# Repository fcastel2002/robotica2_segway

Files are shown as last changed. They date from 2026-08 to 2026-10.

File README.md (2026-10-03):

# Segway con patas extensibles

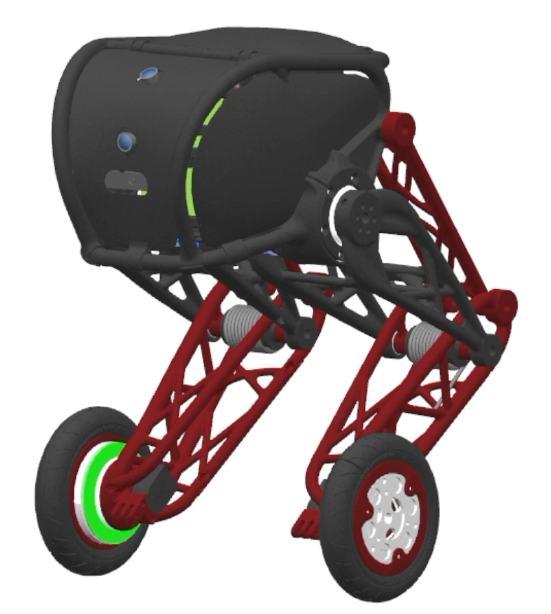
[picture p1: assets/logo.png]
Logo del robot


Trabajo final de **Robótica II**, Universidad Nacional de Cuyo (UNCUYO). Grupo 4: Joaquín Calderón
(modelado), Francisco Castel (diseño mecánico), Matías Armani (simulación en Simulink).

**Este archivo describe el robot tal como es hoy.** Todo lo que había de propuestas anteriores
(mecanismo de Hoeken, motores N20, plantas de simulación de agosto y principios de septiembre) se
borró del árbol el 19/9/2026 y quedó solo en la historia de git; ver la sección 7.

## 1. Qué es el robot

Un robot de dos ruedas que se equilibra como un péndulo invertido (tipo Segway) y que además tiene
**patas extensibles**: cada rueda cuelga de un mecanismo de cuatro barras movido por un servo, así
que el robot puede agacharse, pararse y bajar escalones absorbiendo el golpe con las patas.

- **Equilibrio y avance**: los dos motores de rueda, con encoder, controlados por un LQR sobre la
  inclinación y la velocidad (a diseñar sobre el modelo de la planta completa).
- **Patas**: un servo por pata. El servo es de posición; se le manda una trayectoria de ángulo y su
  lazo interno hace el par. La dinámica de la pata sirve para dimensionarlo, no para comandarlo.
- **Cabina**: caja impresa en PLA que lleva los dos servos, la batería y la electrónica. Los pivotes
  del cuatro barras (A, el eje del servo, y B) están en sus paredes laterales.

## 2. Números vigentes (19/9/2026)

Fuente única de todos los valores: [`modelado/parametros/parametros_fisicos.m`](modelado/parametros/parametros_fisicos.m),
variante `segunda_iteracion`. Si un número de este README no coincide con ese archivo, manda el archivo.

| | Valor | De dónde sale |
|---|---|---|
| Mecanismo | cuatro barras `A B C D` con acoplador rígido `C D P`; `P` es el eje de la rueda | `modelado/geometria/geometria_robot.png` |
| Barras | AD = 112, BC = 108, CD = 40,8, DP = 112 mm (familia 1,40 / 1,35 / 0,51 / 1,40 a escala 80); δ = 164° | medido en los STEP de `diseño_mecanico/segunda_iteracion/completo/step/` |
| Bancada AB | 80 mm a 45° (intención). En el STEP está en 77,9 mm a 46,6°: B quedó 3 mm corto en horizontal, a corregir en `cabeza_v31` | idem |
| Recorrido del servo | 320° (pata estirada, de pie) a 350° (plegada). En la dinámica se usa θ = 360° − servo: 10° plegada, 40° estirada | `parametros_geometria.m` |
| Rueda | Ø66 mm (Rw = 33), 30 g estimados | CAD |
| Servo de pata | **40 kg·cm**, ~58 g, uno por pata. Elegido el 19/9; verificar a qué tensión da los 40 kg·cm | decisión, ver sección 3 |
| Motor de rueda | **JGB37-520 12 V con encoder Hall**, ~152 g. Relación de reducción **sin definir** (la pieza del CAD es la de 319 rpm) | decisión, ver sección 3 |
| Masas estimadas | cabina 667 g (cabeza 207, tapa 114, servos 116, batería 120, electrónica 60, tornillería 50); pata 226 g (barras 44, rueda 30, motor 152); **robot ≈ 1,12 kg** | primera iteración escalada; **pesar todo** |
| Batería | LiPo 3S 11,1 V (propuesta) | |
| Control | 200 Hz (propuesta); electrónica por definir | |

Lo que sale de esos números (par estático del servo, inercia vista por el servo, altura de la cabina,
qué escalón se puede bajar, fuerzas en los pasadores) está en los PDF de `modelado/`, sección 4.

## 3. Decisiones tomadas y por qué

| Fecha | Decisión | Motivo | Dónde está |
|---|---|---|---|
| ago 2026 | Mecanismo de Hoeken con flexor → **cuatro barras** con acoplador rígido | el cuatro barras da una línea casi recta para el eje de rueda con un solo servo, y es más fácil de imprimir | `modelado/geometria/` |
| 2/9 | Barras en la familia 1,40 / 1,35 / 0,51 / 1,40 con δ = 164° | salió de un barrido de proporciones (scripts de Francisco, ya borrados; ver sección 7) | `parametros_fisicos.m` |
| 3/9 | Motor JGA25 de 60 rpm **descartado** | la simulación mostró que con 60 rpm el robot equilibra pero no puede desplazarse ni bajar escalones; hace falta encoder sí o sí | `base_conocimiento/dimensiones_cad_primera_iteracion.md` |
| 14/9 | CAD segunda iteración: barras a **escala 80** | la primera iteración tenía la bancada de 80 mm con barras de escala 100 y perdía la línea recta; Francisco llevó las barras a 80 | `diseño_mecanico/segunda_iteracion/` |
| 19/9 | El modelado pasa a escala 80 para seguir al CAD | eran dos ramas de la misma bifurcación; imprimir es lo caro, así que manda el CAD | `docs/gestion/2026-09-19-auditoria-limpieza.md`, sección 1.2 |
| 19/9 | Servo de **40 kg·cm** | con la geometría de escala 100 la caída de un escalón de 18 cm pedía 22,4 kg·cm de par medio; uno de 25 quedaba justo y uno de 35 no se consigue | `modelado/dinamica/dinamica_resumen.pdf`, sección 10 |
| 19/9 | Motor de rueda **JGB37-520 con encoder** | motorreductor con encoder integrado, 12 V, par de sobra para la rueda de 66 mm. Relación de reducción pendiente | sección 5 |
| 19/9 | `simulacion/planta_v2` (planta completa hecha con Claude) se descarta | el equipo va a rehacer la planta a mano en `modelado/planta/`; queda el banco Simulink de Matías | sección 7 |

## 4. Mapa del repositorio

Nuevo el 1/10/2026: [**modelo dinámico del péndulo invertido, desarrollado paso a paso**](modelado/planta/pendulo_invertido/desarrollo_matematico.md).
Representa el equilibrio y avance con las patas fijas en una postura configurable. La demostración
en MATLAB está en [`simulacion/pendulo_invertido/`](simulacion/pendulo_invertido/README.md); abrir
`SIMULAR_PENDULO_INVERTIDO.m` y pulsar Run. La planta conjunta con flexión dinámica sigue pendiente.

| Carpeta | Qué hay | Responsable |
|---|---|---|
| [`modelado/`](modelado/) | **El modelo del robot.** Una carpeta por tema: `geometria/` (figura con nombres y cotas), `cinematica/` (θ → posiciones, directa e inversa), `dcl/` (diagramas de cuerpo libre), `dinamica/` (Lagrange de la pata, tres casos, caída de escalón, fuerza en el eje del servo), `parametros/` (la fuente única de valores). Cada tema tiene su PDF con la deducción. Ver [`modelado/README.md`](modelado/README.md) | Joaquín (modelado), Matías (API y `parametros/`) |
| [`diseño_mecanico/`](diseño_mecanico/) | `segunda_iteracion/`: el CAD vigente (SolidWorks + STEP). `utilidades/`: piezas compradas (servo, horn, motor, tornillería). `primera_iteracion/`: solo el STEP y las propiedades másicas, que siguen siendo la fuente de las masas. `medir_step/`: scripts para medir el CAD sin SolidWorks. Ver [`diseño_mecanico/README.md`](diseño_mecanico/README.md) | Francisco |
| [`simulacion/`](simulacion/) | `dinamica_pata_v1/`: primera iteración del banco Simulink de la pata (Matías, 14 y 15/9), punto de entrada `INICIAR_DINAMICA_PATA.m`. Ver [`simulacion/README.md`](simulacion/README.md) | Matías |
| [`docs/gestion/`](docs/gestion/) | Plan, guía de QA y traspaso del banco Simulink; auditoría de limpieza del 19/9 | Matías, Joaquín |
| [`base_conocimiento/`](base_conocimiento/) | `dimensiones_cad_primera_iteracion.md`: cotas, masas, centros de masa e inercias medidos sobre el STEP de la primera iteración (2/9). Sigue vigente para masas; para cotas manda la segunda iteración | |
| [`guias_catedra/`](guias_catedra/) | Procedimientos de la cátedra (dimensionamiento de batería, preselección de servos) | |
| [`BACKLOG.md`](BACKLOG.md) | Lo hecho, lo en curso y lo pendiente, con evidencia. Es la lista de tareas del equipo | todos |
| [`AGENTS.md`](AGENTS.md) | Reglas para agentes y colaboradores (PDF → Markdown antes de leer, backlog, diagramas) | |
| `electronica/`, `firmware/`, `referencias/` | Vacías todavía | |

## 5. Qué falta (lo grande)

Detalle y estado en [`BACKLOG.md`](BACKLOG.md).

1. **Pesar** las piezas impresas, el servo y el motor, y reemplazar las masas estimadas.
2. **Definir la relación de reducción** del JGB37-520 y cargar su hoja de datos en `parametros_fisicos.m`.
3. **Medir el servo** en el banco: rigidez del lazo interno (grados de desvío por peso colgado) y par de
   calado real a la tensión que se use. De eso dependen todos los números de la caída de escalón.
4. Corregir en el CAD los 3 mm de la bancada (`cabeza_v31`) y agregar rueda, motor y tapa al ensamble
   de la segunda iteración, para poder cerrar la ficha de masas (CAD-201).
5. **Planta completa** en `modelado/planta/`: péndulo invertido sobre ruedas con la altura del centro de
   masa en función de θ, LQR, motores, contacto. Es el modelo del equilibrio; el banco de Matías es el
   de la pata.
6. Electrónica y firmware: nada empezado.

## 6. Cómo correr las cosas

- Figuras: `python modelado/<tema>/<figura>.py` genera el PNG al lado (Python 3 + matplotlib).
- Dinámica de la pata: abrir `modelado/dinamica/dinamica_pata.m` en MATLAB y correrlo. La sección 1
  tiene los parámetros para editar; las demás imprimen tablas y grafican.
- Tests: desde la raíz, `runtests('modelado/dinamica/tests')` y
  `runtests('simulacion/dinamica_pata_v1/tests')`.
- Banco Simulink: `simulacion/dinamica_pata_v1/INICIAR_DINAMICA_PATA.m` (ver su README).
- PDF: cada `*.tex` se compila con `pdflatex` dos veces desde su carpeta.
- Medir el CAD sin SolidWorks: `python diseño_mecanico/medir_step/step_cuatro_barras.py <ensamble.STEP>`.

## 7. Historia: lo que hubo antes y dónde encontrarlo

Hasta el 19/9 el repo arrastraba tres diseños anteriores y sus simulaciones, y cualquiera que entrara
(persona o IA) no sabía cuál era el vigente. Se borró todo lo anterior al cuatro barras y las plantas
de simulación descartadas. La lista completa, con el motivo de cada borrado, está en
[`docs/gestion/2026-09-19-auditoria-limpieza.md`](docs/gestion/2026-09-19-auditoria-limpieza.md).
Todo sigue en git: `git show eca3ed4:<ruta>` recupera cualquier archivo tal como estaba antes de la limpieza.

| Qué era | Dónde estaba | Por qué ya no |
|---|---|---|
| Mecanismo de Hoeken, robot de 800 g con rueda Ø80 y flexor (documento de dimensionamiento de agosto) | `base_conocimiento/Segway-Pata-Dimensionamiento.docx`, `simulacion/hoekens_dh.html` | reemplazado por el cuatro barras |
| Concepto con motores N20 y microservos SG90 | `diseño_mecanico/proof_of_concept/` | reemplazado |
| Primer boceto del cuatro barras y síntesis en MotionGen | `diseño_mecanico/4_bar_mechanism/`, `4 barras.motiongen` | reemplazado por `primera_iteracion` |
| GUI y barrido de proporciones de las barras (Francisco, 28/8) | `simulacion/simular_pata_segway.m`, `optimizar_barrido_local.m` | cumplieron su función; las proporciones quedaron en `parametros_fisicos.m` |
| CAD primera iteración (bancada 80 a 47,5°, barras 100) | `diseño_mecanico/primera_iteracion/*.SLDPRT` | reemplazado por la segunda; queda el STEP y las masas |
| Plantas Simulink `modelo_base`, `planta_v1` (borradas el 13/9) y `planta_v2` (19/9), con su manual y sus specs | `simulacion/`, `docs/informe_planta_v1/`, `docs/superpowers/` | el equipo rehace la planta a mano; queda el banco de Matías |
| Toolbox de Peter Corke copiado entero (120 MB) | `modelado/cinematica/rtb`, `smtb`, `common` | librería de terceros; `verificar_cinematica_4barras.m` sigue andando sin ella |

## 8. Convenciones

- Origen en A (eje del servo), y hacia arriba. En las figuras de la pata el frente del robot queda a la
  izquierda. Los segmentos se nombran por sus extremos: AB, AD, BC, CD, DP.
- Los PDF no se leen directamente: se convierten a Markdown primero (regla de [`AGENTS.md`](AGENTS.md)).
- Un valor físico vive en un solo lugar, `parametros_fisicos.m`. Las figuras de Python repiten las
  cinco cotas al principio de cada script porque no leen MATLAB; si cambian las barras, cambiarlas ahí también.

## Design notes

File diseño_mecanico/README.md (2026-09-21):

# diseño_mecanico

CAD del robot (SolidWorks 2026). Responsable: Francisco.

| Carpeta | Qué es |
|---|---|
| `segunda_iteracion/` | **El CAD vigente** (14/9/2026): cabina `cabeza_v31`, manivela `eslabon_AD_v2` + `eslabon_AD_tapa`, balancín `eslabon_BC` (interna y externa), acoplador `eslabon_CDP_v2`, servo y horn, tornillería. Ensambles `completo_v2` y `completo_v3`. En `completo/step/` están los STEP exportados de cada pieza y del ensamble, que es lo que puede leer quien no tiene SolidWorks |
| `utilidades/` | Piezas compradas: servo DS3225MG y su horn, motor JGB37-520, rueda de 65 mm, tuercas, tornillos y arandelas |
| `primera_iteracion/` | Solo `completo.STEP` y `mass_properties.md`. Es el CAD anterior (bancada 80 mm a 47,5°, barras a escala 100) y sigue siendo **la fuente de las masas e inercias** del modelo (`base_conocimiento/dimensiones_cad_primera_iteracion.md`) porque el ensamble nuevo no tiene rueda, motor ni tapa |
| `medir_step/` | Dos scripts de Python para medir el CAD sin SolidWorks: `step_agujeros.py <pieza.STEP>` lista los ejes de los agujeros de una pieza y las distancias entre ellos; `step_cuatro_barras.py <ensamble.STEP>` reconstruye el cuatro barras tal como está armado (A, B, C, D, P, largos, ángulo de la bancada, δ, θ de la pose) |

## Cotas de la segunda iteración, medidas sobre los STEP del 14/9

| Cota | Valor | Nota |
|---|---|---|
| AD, BC, CD, DP | 112, 108, 40,8, 112 mm | familia 1,40 / 1,35 / 0,51 / 1,40 a escala 80 |
| δ (D→C a D→P) | 164,0° | |
| AB | **77,9 mm a 46,6°** | la intención es 80 mm a 45°: B está a la altura justa (56,6 mm sobre A) pero 3 mm corto en horizontal (53,5 en vez de 56,6). **Pendiente corregir en `cabeza_v31`** |
| Pose armada | θ = 40,2° (pata estirada); P 148 mm por debajo de A | |
| Las dos patas | idénticas | en la primera iteración estaban en poses distintas |
| Cierre del mecanismo | 0,004 mm | los STEP son consistentes |

El modelo (`modelado/`) usa 80 mm a 45° para la bancada, es decir la intención y no el error de 3 mm.

## Pendientes para Francisco

1. Corregir los 3 mm de B en `cabeza_v31`.
2. Agregar rueda, motor JGB37-520 y tapa al ensamble de la segunda iteración, y exportar el STEP del
   conjunto, para poder cerrar la ficha de masas de esta iteración (CAD-201 del backlog).
3. `segunda_iteracion/` y `segunda_iteracion/completo/` tienen las mismas 19 piezas dos veces (la segunda es
   un Pack and Go con prefijo `asml_` y sufijo `v4`), y hay dos pares de ensambles (v2/v3). Dejar un solo
   juego de piezas y un solo ensamble; SolidWorks referencia por ruta, así que esto lo tiene que hacer quien
   tenga el CAD abierto.
4. La tornillería está repetida en `utilidades/`, `segunda_iteracion/` y `segunda_iteracion/completo/`.
   Dejar una biblioteca.
5. Después de cada cambio en el CAD: exportar los STEP a `completo/step/` y correr
   `python medir_step/step_cuatro_barras.py segunda_iteracion/completo/step/<ensamble>.STEP` para
   confirmar que las cotas siguen siendo las del modelo.

Los archivos `~$*.SLDPRT` que crea SolidWorks al abrir una pieza están en el `.gitignore`; no subirlos.

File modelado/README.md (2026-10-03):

# modelado

Modelo del Segway con patas, ordenado como la checklist de la cátedra: una carpeta por tema. En cada
carpeta hay a lo sumo tres tipos de archivo: un script de Python que genera la figura (`*.py` → `*.png`),
el código MATLAB (`*.m`) y un PDF con la deducción (`*.tex` → `*.pdf`).
El nuevo desarrollo del péndulo invertido se mantiene en Markdown, con ecuaciones y resultados enlazados.

**Geometría vigente: la segunda iteración del CAD (barras a escala 80).** Todo lo de esta carpeta se
actualizó a esa geometría el 19/9/2026. Los valores viven en `parametros/parametros_fisicos.m`; los
scripts de Python repiten las cinco cotas al principio porque no leen MATLAB.

| Carpeta | Qué tiene | Ítem de la checklist que cierra |
|---|---|---|
| `parametros/` | `parametros_fisicos.m`: **la única fuente de valores** (geometría, masas, inercias, servo, motor, contacto, sensores). Variante por defecto `segunda_iteracion`; `corregido` es el baseline histórico a escala 100 | Parámetros consolidados |
| `planta/pendulo_invertido/` | [Desarrollo matemático paso a paso](planta/pendulo_invertido/desarrollo_matematico.md), composición del cuerpo desde las piezas, dinámica no lineal sobre ruedas y linealización A/B. Dos coordenadas (`x`, `phi`), patas fijas en una postura configurable; [script de demostración](../simulacion/pendulo_invertido/SIMULAR_PENDULO_INVERTIDO.m) | Modelo dinámico del equilibrio y avance con patas fijas |
| `geometria/` | `geometria_robot.png`: el robot de perfil con los nombres de las barras (AB, AD, BC, CD, DP), los ángulos (45°, δ, θ) y las cotas del CAD | Diagrama cinemático y grados de libertad |
| `cinematica/` | `parametros_geometria.m` (adaptador de la fuente única, en mm y grados), `cinematica_directa.m` (θ → puntos A, B, C, D, P), `cinematica_inversa.m` (altura → θ), `cinematica_resumen.pdf`. Además `verificar_cinematica_4barras.m`, la verificación del grupo (anda sin el toolbox de Corke; si está instalado, además compara con él) | Cinemática directa e inversa |
| `dcl/` | `dcl_pata.png` (pata parada, θ = 10°, los tres cuerpos separados), `dcl_segway.png` (rueda y cuerpo del péndulo invertido), `dcl_resumen.pdf` con las ecuaciones de equilibrio y el par del servo calculado a mano | Diagramas de cuerpo libre; caso reproducido mediante cálculo manual |
| `dinamica/` | **`dinamica_apoyado.pdf`: el documento para leer**, paso a paso, solo el robot de pie, que es el caso que dimensiona el servo. `dinamica_resumen.pdf`: la referencia completa, con los tres casos (banco, parado, en el aire) y la caída de un escalón. `dinamica_pata.m`: todo el cálculo en un script (parámetros editables en la sección 1, tres casos, agacharse y pararse, verificación contra el DCL, caída de escalón, fuerza radial en el eje del servo). Además la API de Matías (`*_dinamica_pata.m`, con `tests/`) que alimenta el banco Simulink, y `demo_api_dinamica_pata.m` que la muestra. Figuras: `fig_dinamica.png` (los ángulos), `fig_apoyado.png` (alturas y coeficientes de velocidad), `fig_casos.png` (los tres casos) | Torque estático; masas y centros de masa; simulación mínima ejecutable; gráficos |

Convenciones comunes a todo: origen en A (eje del servo), y hacia arriba; θ es el ángulo de AD por
debajo de la horizontal (10° plegada, 40° estirada); el ángulo absoluto del servo que usa la cinemática es
360° − θ. En las figuras de la pata el frente del robot queda a la izquierda; en el DCL del Segway, a la
derecha (vista desde el otro lado).

Hay dos implementaciones de la misma física en `dinamica/`: las funciones locales de `dinamica_pata.m`
(con fricción por pivote, caída de escalón y reacciones) y la API de Matías (más simple, con tablas para
Simulink). Las dos leen los mismos parámetros. Si se cambia una ecuación, cambiarla en las dos.

Desde el 1/10/2026, `planta/pendulo_invertido/` desarrolla el equilibrio con patas fijas. Recalcula el
centro de masa y la inercia al elegir otra postura. El siguiente paso es la planta conjunta con flexión
dinámica de patas, motor eléctrico y control; sustituir una altura variable en el modelo reducido no
incorpora por sí solo ese acoplamiento.

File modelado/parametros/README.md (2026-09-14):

# Parámetros físicos comunes

`parametros_fisicos.m` es la única fuente editable de geometría, masas, inercias, actuadores,
contacto, sensores y ambiente que hoy comparten cinemática, dinámica y simulación.

Las variantes disponibles son:

- `cad`: primera iteración tal como fue medida, con bancada de 80 mm a 47,5°;
- `corregido`: baseline nominal de trabajo, con bancada de 100 mm a 45°.

La segunda iteración CAD no se incorporará hasta contar con cotas y propiedades másicas verificadas.
Los consumidores deben convertir estos valores de ingeniería a SI en sus adaptadores y no volver a
copiar números físicos en otros archivos.

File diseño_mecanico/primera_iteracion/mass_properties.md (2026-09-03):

Mass properties of completo
  Configuration: Predeterminado
  Coordinate system: -- default --

* Includes the mass properties of one or more hidden components/bodies.

Mass = 587.71 grams

Volume = 525422.05 cubic millimeters

Surface area = 299209.35 square millimeters

Center of mass: ( millimeters )
          X = -7.31
          Y = -38.28
          Z = 991.16

Principal axes of inertia and principal moments of inertia: ( grams * square millimeters )
aken at the center of mass.
T
            Ix = (-0.04, 0.99, 0.15)       Px = 3284250.26
            Iy = (-1.00, -0.05, 0.02)      Py = 5222569.89
            Iz = ( 0.03, -0.14, 0.99)      Pz = 6703769.87

Moments of inertia: ( grams * square millimeters )
aken at the center of mass and aligned with the output coordinate system. (Using positive tensor notation.)
T
          Lxx = 5219871.31 Lxy = -79137.38          Lxz = -52793.69
          Lyx = -79137.38      Lyy = 3360073.02     Lyz = 490590.07
          Lzx = -52793.69      Lzy = 490590.07      Lzz = 6630645.69

Moments of inertia: ( grams * square millimeters )
aken at the output coordinate system. (Using positive tensor notation.)
T
          Ixx = 583453919.84 Ixy = 85223.43          Ixz = -4308509.55
          Iyx = 85223.43        Iyy = 580764282.48 Iyz = -21808236.30
          Izx = -4308509.55 Izy = -21808236.30 Izz = 7523221.06

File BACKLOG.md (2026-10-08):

# Backlog persistente — Segway con piernas extensibles

Última actualización: 2026-10-04. Este archivo es la fuente de verdad del trabajo realizado,
en curso y pendiente. Todo cambio futuro debe actualizar aquí su estado y adjuntar evidencia.

Estados: `HECHO`, `EN CURSO`, `PENDIENTE`, `BLOQUEADO`. Prioridades: `P0` crítica, `P1` alta,
`P2` media, `P3` baja.

Plan vigente: [integración de la dinámica en Simulink](docs/gestion/2026-09-14-plan-dinamica-simulink.md).
Traspaso vigente: [dinámica de pata en Simulink](docs/gestion/2026-09-15-handoff-dinamica-simulink.md).

## Estado ejecutivo

- La dinámica de la pata entregada en el commit `c5602f1` es ejecutable y consistente con la
  cinemática y el DCL para los supuestos declarados.
- El banco reducido `simulacion/dinamica_pata_v1/` ya está construido, es regenerable desde código y
  reproduce `banco`, `parado` y `aire`: 12/12 pruebas propias aprobadas.
- El equipo dispone de un único acceso público, `INICIAR_DINAMICA_PATA.m`; el `.slx`, README, pruebas y
  resultados quedan visibles, mientras que constructores y adaptadores se concentran en `interno/`.
- La comunicación visual se limita a tres PNG estables: último Run, comparativo del barrido y validación
  energética. Las métricas completas permanecen en MATLAB sin generar gráficos auxiliares.
- `simulacion/planta_v2/` se eliminó el 19/9 por decisión de Joaquín: la planta completa se rehace a mano en
  `modelado/planta/`. Desde el 1/10 se suma el péndulo invertido con patas fijas al banco de la pata.
- El [péndulo invertido sobre ruedas](modelado/planta/pendulo_invertido/desarrollo_matematico.md) tiene
  deducción completa, cuerpo equivalente calculado desde las piezas, modelo no lineal y linealización A/B.
  [Demostración MATLAB](simulacion/pendulo_invertido/SIMULAR_PENDULO_INVERTIDO.m) ejecutada en R2025b:
  [6/6 grupos físicos aprobados](simulacion/pendulo_invertido/resultados/verificacion.json), cinco archivos
  sin avisos del analizador; faltan la flexión dinámica, la identificación del motor y el control.
- MATLAB R2023b Update 6, Simulink 23.2 y los toolboxes necesarios están instalados.
- Codex usa MATLAB MCP Server v0.13.0 y Simulink Agentic Toolkit 2026.09. La compuerta de librerías
  devuelve `found=false`, `gatePass=true`; `model_overview`, `model_read` y `model_check` funcionan.
- La auditoría MCP del banco terminó `healthy`: sin puertos ni líneas desconectadas. Se corrigieron
  tres líneas huérfanas creadas al vaciar los subsistemas predeterminados.
- Desde el 19/9 la variante por defecto de `parametros_fisicos.m` es `segunda_iteracion` (barras a escala 80,
  servo de 40 kg·cm, motor JGB37-520 de 152 g). Con ella pasan los 8 tests del núcleo y los 4 del banco Simulink.
- El CAD de `segunda_iteracion/` tiene las barras a escala 80 (medido el 19/9 sobre los STEP con
  `diseño_mecanico/medir_step/`); el modelado ya lo sigue. Faltan en el ensamble la rueda, el motor y la tapa,
  así que las masas siguen siendo las de la primera iteración escaladas: pesar las piezas es la primera pendiente.

## Trabajo realizado

| ID | Pri. | Estado | Fecha | Tarea | Evidencia / resultado |
|---|---:|---|---|---|---|
| PEN-001 | P0 | HECHO | 2026-10-01 | Desarrollar el péndulo invertido sobre ruedas, con patas fijas configurables, deducción paso a paso y script MATLAB legible (Codex) | [Capítulo matemático](modelado/planta/pendulo_invertido/desarrollo_matematico.md), [script](simulacion/pendulo_invertido/SIMULAR_PENDULO_INVERTIDO.m), [corrida](simulacion/pendulo_invertido/resultados/resultado_base.md), [6/6 comprobaciones físicas](simulacion/pendulo_invertido/resultados/verificacion.json); MATLAB R2025b, cinco archivos con 0 avisos; CoM/inercia recalculados para 10°, 25° y 40°; alcance de patas fijas explícito |
| PEN-002 | P1 | HECHO | 2026-10-03 | Cambiar la convención del péndulo invertido a sentido antihorario positivo (ángulos, pares y momentos) en el capítulo, el modelo MATLAB y la verificación | [Capítulo](modelado/planta/pendulo_invertido/desarrollo_matematico.md) §3 y ecs. (9)–(56), [verificación 6/6](simulacion/pendulo_invertido/resultados/verificacion.json), [corrida regenerada](simulacion/pendulo_invertido/resultados/resultado_base.md) con A/B iguales a (56); MATLAB R2025b |
| PEN-003 | P1 | HECHO | 2026-10-04 | Redactar el desarrollo del péndulo invertido centrado en el espacio de estados (sin scripts), estilo libro, con diagramas svgbob; responde por qué el capítulo previo no lo usa, el atajo de linealización por energías y el seno como perturbación medida con IMU | [Capítulo](modelado/planta/pendulo_invertido/desarrollo_espacio_estados.md), [diagramas](modelado/planta/pendulo_invertido/diagramas/) (`.bob`/`.svg`/`.png`); A, B y autovalores iguales a la [corrida base](simulacion/pendulo_invertido/resultados/resultado_base.md); determinante de controlabilidad, cero RHP, observabilidad con solo IMU, cancelación de gravedad y ganancias del lazo interno verificados numéricamente con numpy (fuera del repo); contrastado el 2026-10-04 con las págs. 3-12/3-13, 7-4/7-5 y 14-11 a 14-15 del libro de Åström–Murray (sin discrepancias; se corrigió la cota del cero RHP a 0,6·z₀); sin ejecutar MATLAB |
| DOC-104 | P2 | HECHO | 2026-10-04 | Eliminar de `AGENTS.md` la regla que prohibía leer PDFs directamente, por decisión explícita del usuario (Francisco Castel) | [`AGENTS.md`](AGENTS.md) sin la sección «Regla obligatoria para archivos PDF»; se borró la conversión intermedia `referencias/_md/` (no versionada) |
| AUD-001 | P0 | HECHO | 2026-09-14 | Inventariar repositorio, historia y estructura sin leer PDFs directamente | Revisión de archivos fuente `.md`, `.tex` y `.m`; PDFs omitidos según `AGENTS.md` |
| AUD-002 | P0 | HECHO | 2026-09-14 | Revisar el commit de dinámica de `joacalde` | Commit `c5602f1`: tres casos `banco`, `parado`, `aire`; ecuación de Lagrange, DCL y simulación ODE |
| AUD-003 | P0 | HECHO | 2026-09-14 | Ejecutar y analizar `dinamica_pata.m` | MATLAB sin errores ni avisos de `checkcode`; 11,62 kg·cm estático, 16,2 kg·cm pico en maniobra |
| AUD-004 | P0 | HECHO | 2026-09-14 | Comparar dinámica y cinemática independiente | Error máximo en la posición de `P`: `3,735e-16 m` |
| AUD-005 | P0 | HECHO | 2026-09-14 | Ejecutar regresión de `simulacion/planta_v2/tests` | 21/22 pasan; falla `test_bloques/test_escalera_y_flexor`, error de posición final `0,0670 m` > `0,05 m` |
| AUD-006 | P1 | HECHO | 2026-09-14 | Restaurar artefactos `.slx` regenerados por las pruebas | Worktree devuelto al estado previo antes de crear esta documentación |
| ENV-001 | P0 | HECHO | 2026-09-14 | Auditar MATLAB/Simulink y toolboxes | MATLAB R2023b Update 6; Simulink, Symbolic Math, Control System, Simscape Multibody y Simulink Test 23.2 |
| MCP-001 | P0 | HECHO | 2026-09-14 | Auditar MCP instalado y versión upstream | Claude usa `C:/Users/matia/.claude/matlab-mcp-core-server.exe` v0.10.0; Codex: ninguno; upstream: v0.13.0 |
| DOC-001 | P0 | HECHO | 2026-09-14 | Crear plan y backlog persistentes | Este archivo y `docs/gestion/2026-09-14-plan-dinamica-simulink.md` |
| PAR-001 | P0 | EN CURSO | 2026-09-19 | Consolidar parámetros físicos compartidos | Variante `segunda_iteracion` (escala 80, servo 40 kg·cm, JGB37-520) por defecto desde el 19/9; Python y `.tex` de `modelado/` actualizados; resta cargar masas pesadas y la relación del motor |
| DYN-101 | P0 | HECHO | 2026-09-14 | Convertir la derivación en API reutilizable | Funciones públicas de parámetros, términos, estado, normal, modos y tablas en `modelado/dinamica/`; script histórico conservado como demo |
| DYN-102 | P0 | HECHO | 2026-09-14 | Formalizar `n_patas` | Eliminado el factor fijo `2`; equivalencia para dos patas y caso de tres patas cubiertos por tests |
| DYN-104 | P1 | HECHO | 2026-09-14 | Generar tablas trazables para Simulink | Seis tablas 2-D (`theta`, caso), comparadas contra las funciones directas con error controlado |
| SIM-101 | P0 | HECHO | 2026-09-14 | Construir el banco reducido Simulink | `dinamica_pata_simulink.slx`, generador, escenarios, runner, pruebas y README en `simulacion/dinamica_pata_v1/` |
| SIM-102 | P0 | HECHO | 2026-09-14 | Implementar las tres reducciones | `banco`, `parado` y `aire` comparten la misma ecuación y seleccionan tablas por caso |
| SIM-103 | P0 | HECHO | 2026-09-14 | Auditar estructura mediante MCP | `model_overview`/`model_read`: 3 subsistemas internos; `model_check`: `healthy`, sin advertencias |
| TST-101 | P0 | HECHO | 2026-09-14 | Verificar MATLAB vs Simulink | Errores suaves máximos por debajo de `1e-5 rad` y `1e-4 rad/s`; términos estáticos coincidentes |
| TST-102 | P1 | HECHO | 2026-09-14 | Verificar energía y sensibilidad al solver | Deriva conservativa `7,79e-10`; residuo disipativo `3,76e-8`; comparación de tres configuraciones documentada |
| RUN-101 | P1 | HECHO | 2026-09-14 | Ejecutar el primer barrido reproducible | `simulacion/dinamica_pata_v1/resultados/corridas_baseline_2026-09-14.mat` y resumen Markdown |
| ARC-101 | P0 | HECHO | 2026-09-15 | Priorizar bloques nativos y legibilidad visual en el banco reducido | Cero bloques `MATLAB Function`; `test_construccion_reproducible` verifica la condición |
| DOC-102 | P1 | HECHO | 2026-09-15 | Documentar apertura, ejecución, interpretación y QA del banco | [Guía de QA](docs/gestion/2026-09-15-guia-qa-dinamica-simulink.md) con comandos copiables, diagnóstico de `Invalid expression`, umbrales y checklist |
| DOC-103 | P0 | HECHO | 2026-09-15 | Preparar traspaso autocontenido para continuar la dinámica Simulink en una sesión limpia | [Documento de traspaso](docs/gestion/2026-09-15-handoff-dinamica-simulink.md) con origen, arquitectura, comandos, evidencia, limitaciones, estado Git y próximos pasos; QA final 12/12 |
| ORG-101 | P0 | HECHO | 2026-09-15 | Consolidar el banco en un punto de entrada único y separar detalles internos | [`INICIAR_DINAMICA_PATA.m`](simulacion/dinamica_pata_v1/INICIAR_DINAMICA_PATA.m), [`interno/`](simulacion/dinamica_pata_v1/interno/), 12/12 pruebas y ejecución directa con Run verificadas |
| VIS-101 | P0 | HECHO | 2026-09-15 | Generar figuras automáticas y comunicables después de cada Run, barrido y análisis energético | [`resultados/figuras/README.md`](simulacion/dinamica_pata_v1/resultados/figuras/README.md), [`resumen_equipo.png`](simulacion/dinamica_pata_v1/resultados/figuras/resumen_equipo.png), [`energia_solver.png`](simulacion/dinamica_pata_v1/resultados/figuras/energia_solver.png); botón Run verificado y QA 12/12 aprobado |
| VIS-102 | P1 | HECHO | 2026-09-15 | Simplificar la exportación visual para conservar únicamente PNG | Exportador validado con 0 avisos; regeneración produjo 12 PNG y ningún PDF/FIG; se retiraron 24 artefactos redundantes de [`resultados/figuras/`](simulacion/dinamica_pata_v1/resultados/figuras/) |
| VIS-103 | P1 | HECHO | 2026-09-15 | Reducir sobregráficos y análisis visual redundante | Tres PNG estables en [`resultados/figuras/`](simulacion/dinamica_pata_v1/resultados/figuras/): Run con ángulo/esfuerzo/contacto/KPI, barrido con tres márgenes y energía con dos verificaciones; se retiraron nueve PNG redundantes |
| AUD-007 | P0 | HECHO | 2026-09-19 | Auditar contenido obsoleto y coherencia CAD ↔ modelado | [Auditoría de limpieza](docs/gestion/2026-09-19-auditoria-limpieza.md): conflicto de git commiteado en `dinamica_pata.m` (`eca3ed4`, versión limpia en el stash `661c39f`); CAD de segunda iteración a escala 80 (AB 77,9 mm a 46,6°, AD 112, BC 108, CD 40,8, DP 112) contra modelado a escala 100; lista de borrado por nivel de seguridad. Nada borrado todavía |
| FIX-001 | P0 | HECHO | 2026-09-19 | Resolver el conflicto de git commiteado en `dinamica_pata.m` | Restaurado desde el stash `661c39f` (444 líneas, sin marcadores); el demo de Matías quedó en `demo_api_dinamica_pata.m` |
| LIM-001 | P0 | HECHO | 2026-09-19 | Borrar todo lo anterior al cuatro barras, las plantas descartadas y los duplicados | Corke vendoreado, OneNote, `proof_of_concept`, `4_bar_mechanism`, Hoeken, scripts de síntesis, `informe_planta_v1`, specs, `.codebase-memory`, locks de SolidWorks, primera iteración (salvo STEP y masas), `planta_v2` (su `git rm` lo ejecuta Joaquín: bloqueado por permisos del agente). README raíz y de cada carpeta reescritos |
| PAR-002 | P0 | HECHO | 2026-09-19 | Pasar todo `modelado/` a la geometría del CAD (escala 80) con el motor y el servo elegidos | 7 figuras regeneradas, 4 PDF recompilados, `dinamica_pata.m` corrido: 9,06 kg·cm estático, 19,9 kg·cm para 18 cm de escalón (límite 47 cm con 40 kg·cm), tests 8/8 y Simulink 4/4 |
| ELE-001 | P1 | HECHO | 2026-09-22 | Investigar corriente del JGB37-520 y aptitud preliminar del DRV8871 | [Comparación con fichas de fabricante y TI](electronica/seleccion_driver_jgb37_520.md): 12 V/319 rpm ≈ 0,17 A nominales y 1,2 A bloqueado en una variante; 3,6 A del driver son de pico; confirmar bobinado real |
| ELE-002 | P1 | PENDIENTE | 2026-09-22 | Confirmar la relación del motor elegido y validar driver con medidas eléctricas y térmicas | [Publicación concreta y criterios](electronica/seleccion_driver_jgb37_520.md): 12 V, ≤1 A nominal, 2,3 A bloqueado; anuncio ofrece varias relaciones sin fijar la entregada |
| ELE-003 | P1 | HECHO | 2026-09-22 | Investigar corriente publicada del servo de 40 kg·cm elegido | [Registro de la publicación y comparación](electronica/servo_40kg_corriente.md): ficha «Genérica / Generic» sin tensión ni corriente; no hay máximo verificable para este producto |
| ELE-004 | P1 | PENDIENTE | 2026-09-22 | Obtener ficha o medir el servo comprado y dimensionar su alimentación | [Datos pendientes y margen provisional](electronica/servo_40kg_corriente.md); dos servos por robot, medir pico y carga simultánea |
| ELE-005 | P1 | HECHO | 2026-09-22 | Proponer fusibles de compra para LiPo 3S, motores y BEC | [Cálculo y ubicación](electronica/fusibles_propuesta_inicial.md): 15 A principal, 5 A por motor, 10 A entrada de BEC, sujetos a calibre de cables y corriente de entrada del BEC definitivo |
| ELE-006 | P1 | HECHO | 2026-09-22 | Revisar conexión INA219 con ESP32 y compatibilidad del carrito | [Conexión, límites y ajustes de compra](electronica/ina219_esp32_y_carrito.md), basados en la [planilla de materiales](Materiales%20-%20Segway%20-%20Robotica%202.xlsx), las capturas y fichas oficiales de TI/Espressif; pendiente de validación física: corriente real y capacidad de los módulos genéricos |
| ELE-007 | P1 | HECHO | 2026-09-22 | Definir alimentación de DRV8871 desde LiPo 3S y protección de batería | [Distribución, BMS y conector](electronica/alimentacion_lipo_3s.md): VM directo a 3S; balanceo y protección por subtensión externos; Mini-Tamiya de la batería elegida difiere del XT60 previsto |
| ELE-008 | P1 | HECHO | 2026-09-22 | Verificar alcance de INA226, alarma y BMS 3S para LiPo del carrito | [Criterio revisado](electronica/ina226_bms_3s.md): foto confirma `R100`, `VBUS` y `ALERT`; válido como alarma de tensión total sin corriente por shunt; para corriente total requiere shunt y camino de potencia distintos; operación autónoma requiere corte por celda |
| ELE-009 | P1 | HECHO | 2026-09-22 | Evaluar ACS712 para corriente de motores y batería con ESP32 | [Selección y conexión](electronica/medicion_corriente_acs712.md): dos ±5 A por motor y uno ±20 A total, condicionados a la capacidad de los módulos; divisores 1:2 a ADC1 del ESP32, calibración y filtrado |
| ELE-010 | P2 | HECHO | 2026-09-22 | Aclarar mediciones simultáneas de tensión, corriente y potencia del INA226 en la rama de 5 V | [Funcionamiento y conexión](electronica/ina226_bms_3s.md): VBUS y shunt son mediciones directas; corriente/potencia requieren calibración; R100 útil en lógica 5 V solo si pico <0,819 A; dos módulos I²C requieren direcciones distintas |
| ELE-011 | P1 | HECHO | 2026-09-22 | Dimensionar INA226 para dos ramas de motor y reutilizar VBUS para batería | [Propuesta de dos módulos](electronica/ina226_dos_motores.md): R010 por rama, VBUS común para LiPo, ubicación en VM, direcciones distintas; corriente medida es la entrada del driver, no la instantánea del bobinado |
| ELE-012 | P1 | HECHO | 2026-09-22 | Evaluar resistencias de cemento de 5 W como shunts externos del INA226 | [Evaluación del surtido](electronica/ina226_dos_motores.md): 0,01 Ω/5 W utilizable para prototipo, condicionado a conexión Kelvin y calibración; preferir shunts de cuatro terminales y 1 % para montaje definitivo |

## Próximo hito: banco Simulink de la dinámica de la pata

| ID | Pri. | Estado | Dependencias | Tarea | Criterio de aceptación |
|---|---:|---|---|---|---|
| CAD-201 | P0 | EN CURSO | Equipo mecánico | Exportar la segunda iteración a STEP y registrar cotas, masas, CoM e inercias por pieza | Cotas medidas el 19/9 sobre los STEP del 14/9 (AD 112, BC 108, CD 40,8, DP 112; AB 77,9 mm a 46,6°, B 3 mm corto) con `diseño_mecanico/medir_step/`; faltan rueda, motor y tapa en el ensamble para las masas |
| PAR-001 | P0 | EN CURSO | 2026-09-19 | Consolidar parámetros físicos compartidos | Variante `segunda_iteracion` (escala 80, servo 40 kg·cm, JGB37-520) por defecto desde el 19/9; Python y `.tex` de `modelado/` actualizados; resta cargar masas pesadas y la relación del motor |
| MCP-002 | P0 | HECHO | 2026-09-14 | Instalar/actualizar MATLAB MCP Server v0.13.0 y Simulink Agentic Toolkit para Codex | Servidor v0.13.0, toolkit 2026.09, 24 skills; `detect_matlab_toolboxes` y `model_overview` invocados desde una sesión Codex nueva |
| MCP-003 | P0 | HECHO | 2026-09-14 | Configurar Windows y tiempos de espera | Modo `existing`, `env_vars = ["WINDIR"]`, telemetría deshabilitada, `startup_timeout_sec = 60` y `tool_timeout_sec = 600`; ver [registro](docs/gestion/2026-09-14-entorno-matlab-mcp.md) |
| DYN-101 | P0 | HECHO | PAR-001 | Separar el script monolítico en funciones reutilizables | API pública y demo disponibles; 8/8 tests del núcleo aprobados |
| DYN-102 | P0 | HECHO | DYN-101 | Eliminar supuestos codificados como `2` y formalizar `n_patas` | Resultados idénticos para `n_patas=2`; prueba coherente con `n_patas=3` aprobada |
| DYN-103 | P0 | EN CURSO | DYN-101 | Añadir límites físicos y señal explícita de pérdida de contacto | Topes y supervisor MATLAB implementados; resta transición automática `parado` ↔ `aire` y prueba de recontacto en Simulink |
| DYN-104 | P1 | HECHO | DYN-101 | Generar tablas trazables de `Ieq`, `dIeq`, `dV`, `wP` y cinemática | Error de tabla < 0,1 % frente a cálculo directo en toda la carrera; variante y datos fuente registrados |
| SIM-101 | P0 | HECHO | DYN-101, DYN-104 | Construir `simulacion/dinamica_pata_v1/dinamica_pata_simulink.slx` | Modelo regenerable, abre, compila y corre en R2023b; interfaces documentadas |
| SIM-102 | P0 | HECHO | SIM-101 | Implementar los tres bancos reducidos como variantes de validación | `banco`, `parado` y `aire` reproducen los términos MATLAB sin ecuaciones duplicadas |
| TST-101 | P0 | HECHO | SIM-101 | Crear pruebas MATLAB vs Simulink | Casos suaves: `theta < 1e-5 rad`, `dtheta < 1e-4 rad/s`; suite de equivalencia aprobada |
| TST-102 | P1 | HECHO | SIM-101 | Verificar conservación/disipación de energía y sensibilidad al solver | Resultado y MAT en `simulacion/dinamica_pata_v1/resultados/`; solver nominal respaldado para dinámica suave |
| TST-103 | P0 | PENDIENTE | DYN-103 | Verificar topes, pérdida de contacto y recontacto como eventos híbridos | Sin normal negativa silenciosa; secuencia de modos y penetración máxima documentadas |
| CTL-101 | P1 | PENDIENTE | TST-101 | Evaluar prealimentación de gravedad en el servo del banco | Error estático en 10°, 25° y 40° cuantificado y reducido sin ocultar saturaciones |
| RUN-101 | P1 | HECHO | TST-101 | Ejecutar barridos básicos de maniobra y parámetros | `.mat` y resumen `.md` versionables con parámetros, solver y commit base registrados |

## Integración con la planta completa

| ID | Pri. | Estado | Dependencias | Tarea | Criterio de aceptación |
|---|---:|---|---|---|---|
| V2-001 | P0 | CANCELADO | — | Diagnosticar la prueba fallida `escalera_flexor` | `planta_v2` eliminada el 19/9 (decisión de Joaquín; ver [auditoría](docs/gestion/2026-09-19-auditoria-limpieza.md)) |
| V2-002 | P0 | CANCELADO | — | Resolver la edición manual del `.slx` no reflejada por su constructor | `planta_v2` eliminada el 19/9 |
| PLT-301 | P0 | PENDIENTE | TST-101, V2-001 | Especificar planta exacta con `q=[x_P,y_P,phi,theta]` | Documento de ecuaciones, convenciones y balance de energía aprobado |
| PLT-302 | P0 | PENDIENTE | PLT-301 | Derivar/generar `M(q)`, términos centrífugos/Coriolis, gravedad y fuerzas generalizadas | Matriz simétrica definida positiva en toda la carrera; tres reducciones coinciden con DYN-101 |
| PLT-303 | P0 | PENDIENTE | PLT-302 | Crear la planta completa en `modelado/planta/` (a mano, sin heredar `planta_v2`) y después su banco en `simulacion/` | Piso plano sin control y casos reducidos pasan; artefactos regenerables desde código |
| PLT-304 | P1 | PENDIENTE | PLT-303 | Integrar contacto, ruedas, motores, batería, sensores y controlador existentes | Interfaces equivalentes o migración documentada; sin señales algebraicas ocultas |
| CTL-301 | P0 | PENDIENTE | PLT-304 | Relinealizar y rediseñar el LQR en varios largos de pata | Controlabilidad verificada; márgenes, saturación y puntos de operación versionados |
| TST-301 | P0 | CANCELADO | — | Regresión `planta_v2` vs `planta_v3` en piso plano | Sin `planta_v2` no hay regresión heredada; la planta nueva se valida contra el DCL y la dinámica de la pata |
| RUN-301 | P1 | PENDIENTE | CTL-301, TST-301 | Simular equilibrio, empujones, agacharse/pararse y avance | Métricas y gráficas versionadas; casos nominales y extremos |
| RUN-302 | P1 | PENDIENTE | RUN-301 | Simular escalón y escalera con/sin flexor | Solo después de validar contacto y piso plano; impacto y sensibilidad al paso documentados |
| VAL-301 | P1 | PENDIENTE | Prototipo físico | Identificar parámetros reales de servo, rueda, contacto y masas | Ensayos y datos crudos versionados; parámetros actualizados con incertidumbre |
| DOC-301 | P1 | PENDIENTE | RUN-302 | Actualizar informe y manual del modelo | Ecuaciones, supuestos, trazabilidad y resultados concordantes con `planta_v3` |

## Reglas de mantenimiento

1. Al iniciar una tarea, cambiarla a `EN CURSO`, agregar fecha y responsable.
2. Al finalizar, enlazar evidencia reproducible y recién entonces marcar `HECHO`.
3. Si aparece trabajo nuevo, asignar un ID estable; no ocultarlo dentro de comentarios del código.
4. Los resultados deben indicar versión de parámetros, variante CAD, solver, tolerancias y commit.
5. Los PDFs no son fuente de lectura: usar el `.md` o `.tex` editable correspondiente.

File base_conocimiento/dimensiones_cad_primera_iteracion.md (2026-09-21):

# Dimensiones y propiedades másicas del CAD — `primera_iteracion` (2026-09-02)

> **Nota (19/9/2026):** las cotas de este documento son de la primera iteración y quedaron superadas por
> `diseño_mecanico/segunda_iteracion` (barras a escala 80: AD 112, BC 108, CD 40,8, DP 112; ver
> `diseño_mecanico/README.md`). Las masas, centros de masa e inercias de las secciones 6 y 7 siguen siendo la
> única fuente disponible; `modelado/parametros/parametros_fisicos.m` las escala a 80.

Fuente: `diseño_mecanico/primera_iteracion/completo.STEP` (SolidWorks 2026, AP203).
Método: parseo del STEP (posiciones de ensamble y centros de agujeros) + mallado tetraédrico en
MATLAB R2023b (`importGeometry` + `generateMesh`) para volumen, centroide e inercia de cada pieza.
SolidWorks no está instalado en la PC de trabajo, así que **no hay materiales ni masas en el CAD**:
las masas de piezas impresas son volumen × densidad efectiva estimada (ver tabla).

## 1. Marco de referencia usado

Plano sagital, origen en **A** (eje del servo de hombro):

- `x_atrás` positivo hacia atrás (la pata se pliega hacia atrás, igual que en `params_robot.m`).
- `y_arriba` positivo hacia arriba.
- `lateral` positivo hacia la pata derecha.

En el STEP: X global = lateral, Y global = vertical, Z global = adelante. A está en
(Y, Z) = (−3.46, 1002.46) mm del STEP.

## 2. Mecanismo de cuatro barras (por pata)

| Elemento | Valor CAD | Nota |
|---|---|---|
| Bancada AB | **80.0 mm** | B queda 54.0 mm atrás y 59.0 mm arriba de A → **47.5°** |
| Manivela AD (servo) | **140.0 mm** | `eslabon_AD`, espesor 4 mm, agujero Ø20 en A, Ø8 en D |
| Balancín BC | **135.0 mm** | `eslabon_BC`, 20 mm de ancho, 4 mm, agujeros Ø8 |
| Acoplador CD | **51.0 mm** | parte de `eslabon_CDP` |
| Pata DP | **140.0 mm** | parte de `eslabon_CDP`, 4 mm de espesor |
| δ (D→C hacia D→P) | **164.0°** | C está a 49.02 mm de D sobre la prolongación de PD, desplazado 14.06 mm |
| Recorrido del servo previsto | 320° a 350° (30°) | según `params_robot` / GUI; el CAD está armado en θ ≈ 311° (derecha) y 315° (izquierda) |

**Hallazgo importante.** Las barras son exactamente la familia `grupo` con **s = 100 mm**
(1.40 / 1.35 / 0.51 / 1.40 × 100), pero la bancada AB del `cabeza_v31` es de **80 mm a 47.5°**,
no de 100 mm a 45°. `params_robot('s',80)` da AD = 112, BC = 108, CD = 40.8, DP = 112: **no
reproduce el CAD**. Consecuencia cinemática (barrido 320–350°, calculado con las cotas reales):

| Métrica | Diseño (`s`=80, AB=s) | CAD real (AB=80, barras de s=100) |
|---|---|---|
| Carrera del eje de rueda | 107 mm | **103.5 mm** |
| Desvío horizontal del eje | 0.46 mm (0.4 %) | **9.0 mm (8.7 %)** |
| Offset del eje respecto de A | ≈ 0 | −1 a +7 mm (−6 mm en la pose armada) |
| Ángulo de transmisión mínimo | 58° | 60° |
| Ganancia dz/dθ | 204 mm/rad | **198 mm/rad** |

La recta se degrada 20× porque la bancada no está a escala. Dos formas de corregirlo: llevar AB a
100 mm a 45° en `cabeza_v31`, o reimprimir las barras a escala 80 (AD 112, BC 108, CD 40.8, DP 112).

## 3. Posiciones de nudos en la pose armada (pata derecha, θ ≈ 311.5°)

| Punto | x_atrás [mm] | y_arriba [mm] |
|---|---|---|
| A (servo) | 0 | 0 |
| B | +54.0 | +59.0 |
| D | +92.8 | −104.8 |
| C | +117.4 | −60.2 |
| P (eje de rueda) | −6.0 | −204.0 |
| Centro del cilindro de la cabeza | −18.5 | +21.0 |

La pata izquierda está armada en θ ≈ 315° (P en −4.1, −193.5): las dos patas no están vinculadas
entre sí en el ensamble.

## 4. Alturas (con rueda Ø66 del CAD)

| Pose | A sobre el suelo | Tope de la tapa sobre el suelo |
|---|---|---|
| θ = 320° (más alto del recorrido previsto) | 211.7 mm | **286 mm** |
| θ = 350° (agachado) | 108.2 mm | **182 mm** |
| Pose armada en el CAD (θ ≈ 311°) | 237 mm | 311 mm |

Fondo de la cabeza: 29 mm por debajo de A → despeje mínimo al suelo 79 mm en la pose agachada.

## 5. Cuerpo, rueda y actuadores

| Pieza | Dimensiones | Detalle |
|---|---|---|
| `cabeza_v31` (cabina) | 150 ancho × 142 fondo × 104.5 alto mm | caja abierta con laterales en U (R50), **pared 3 mm**; lleva los pivotes A y B en las paredes laterales |
| `tapa_cabeza` | 150 × 133 × 103 mm | techo semicilíndrico R53 exterior + placa, 3 mm |
| Rueda `wheel` | **Ø66 × 25 mm** (rueda comercial de 65 mm) | radio de rodadura **33 mm** — ojo: `params_robot` y el .docx usan Ø80 |
| Trocha (entre planos medios de rueda) | **194 mm** | ancho total ≈ 219 mm |
| Planos de las barras | lateral +70/+74 (der.) y −84/−88 (izq.) | por fuera de la cabina (±75) |
| Motor rueda `JGA25-370 12V 60RPM` | Ø25 × 70.5 mm (con eje D4) | montado en P, del lado interno de la pata; rueda del lado externo |
| Servo `DS3225MG` | 40 × 20 × 40.5 mm | en A, dentro de la cabina, eje hacia afuera |

## 6. Masas estimadas

| Pieza | Volumen CAD [cm³] | Base de la estimación | Masa unit. [g] | Cant. | Total [g] |
|---|---|---|---|---|---|
| `cabeza_v31` | 172.9 | PLA, paredes 3 mm ≈ macizo, ρ = 1.20 | 207 | 1 | 207 |
| `tapa_cabeza` | 94.9 | PLA, ρ = 1.20 | 114 | 1 | 114 |
| `eslabon_AD` | 26.3 | PLA, placa 4 mm, ρ efectiva 1.10 | 29 | 2 | 58 |
| `eslabon_BC` | 6.3 | idem | 7 | 2 | 14 |
| `eslabon_CDP` | 17.7 | idem | 19.5 | 2 | 39 |
| `wheel` Ø66 | 26.7 | rueda comercial 65 mm (goma + cubo) | 30 | 2 | 60 |
| `JGA25-370` | 25.7 (sólido) | catálogo (motorreductor 25D) | ≈ 95 | 2 | 190 |
| `DS3225MG` | — | hoja de datos | 60 | 2 | 120 |
| **Subtotal modelado en CAD** | | | | | **802** |
| Batería LiPo 3S 1000–1500 mAh | — | no está en el CAD | 100–150 | 1 | 100–150 |
| Electrónica (ESP32, driver, IMU, BEC, cables) | — | no está en el CAD | 60–80 | | 60–80 |
| Tornillería, ejes, rodamientos | — | no está en el CAD | 40–60 | | 40–60 |
| **Total estimado del robot** | | | | | **≈ 1000–1090** |

El objetivo del `.docx` era 800 g y `params_robot` asume 856 g. Casi todo el exceso está en la
cabina + tapa (≈ 320 g en PLA con pared de 3 mm) y en los motorreductores (190 g).

## 7. Propiedades para la dinámica (plano sagital, pose armada)

| Magnitud | Valor | Comentario |
|---|---|---|
| Masa suspendida m_b (todo menos ruedas y motores) | 552 g sin batería/electrónica → **≈ 730–780 g** con ellas | |
| CoM del cuerpo respecto de A | (+7.9, −2.2) mm sin batería → **(+1.4, +3.5) mm** con batería y electrónica centradas en la cabeza | queda prácticamente sobre A |
| Masa no suspendida m_w (2 ruedas + 2 motores) | **250 g** | 25 % del robot |
| Inercia de cabeceo del cuerpo J_b (alrededor de su CoM) | 2.74e−3 kg·m² sin batería → **≈ 3.0e−3 kg·m²** | de la malla del CAD |
| Largo de péndulo l (eje de rueda → CoM del cuerpo) | ≈ 200 mm en la pose armada; **≈ 80 a 182 mm** en el recorrido 350°→320° | |
| Inercia de una rueda J_w | ≈ 2e−5 kg·m² | disco de 30 g y 33 mm |
| Inercia del rotor reflejada al eje | **≈ 5e−3 a 8e−3 kg·m² por rueda** | rotor ≈ 5e−7 kg·m² × N² (N ≈ 100–125). Equivale a 4.5–7 kg por rueda vistos desde el suelo: domina la dinámica de la rueda |
| Par estático de hombro | ≈ 0.7 N·m = **7.2 kg·cm por servo** (m_b·g·G/2 con G = 0.198 m/rad) | DS3225MG: 24.5 kg·cm a 6.8 V → margen 3.4× |
| Límite de adherencia por rueda (μ = 0.7, 1.0 kg) | 3.4 N → **0.113 N·m = 1.15 kg·cm** | el JGA25 60 rpm (≈ 15–20 kg·cm de bloqueo) sobra 15×; la rueda patina antes |
| Velocidad máxima | 60 rpm × 2π × 0.033 m = **0.21 m/s** | limitante: el robot no puede "correr" para recuperar inclinaciones grandes |

## 8. Datos de catálogo usados

- **DS3225MG**: 21 kg·cm / 0.15 s/60° a 5 V; 24.5 kg·cm / 0.13 s/60° a 6.8 V; corriente de bloqueo
  1.9–2.3 A; 60 g; 40 × 20 × 40.5 mm; 4.8–6.8 V.
- **JGA25-370 12 V**: hoja de Seeed (variante 350 rpm, 1:21): vacío 0.1 A, máx. eficiencia 245 rpm /
  0.65 A / 1.4 kg·cm / 2.4 W, bloqueo 5.2 kg·cm / 2.2 A. Para la variante de 60 rpm (1:100–1:125)
  se extrapola bloqueo ≈ 15–20 kg·cm y misma corriente de bloqueo. **Verificar con la hoja del
  motor comprado**; la masa (~95 g) y la relación exacta tampoco están confirmadas.

## 9. Diferencias entre el CAD y la documentación

| Tema | `.docx` (dimensionamiento) | `params_robot` (zip) | CAD `primera_iteracion` |
|---|---|---|---|
| Mecanismo | Hoeken clásico, a = 12.69 mm | cuatro barras `grupo`, s = 80 | cuatro barras `grupo` s = 100 con AB = 80 |
| Motores de rueda | BLDC gimbal + FOC | motorreductor 0.35 N·m, 300 rpm | JGA25-370 12 V 60 rpm |
| Rueda | Ø80 | Ø80 | **Ø66** |
| Flexor / amortiguación | arco de PA12, 40 mm de carrera | no | no (barras rígidas) |
| Masa total | 800 g objetivo | 856 g | ≈ 1.0–1.1 kg estimado |
| Altura de pie | ≈ 200 mm máx. (cátedra) | 152–259 mm | 182–286 mm (311 mm en la pose armada) |

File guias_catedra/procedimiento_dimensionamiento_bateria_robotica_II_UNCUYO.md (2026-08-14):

**Objetivo.** Seleccionar rápidamente una batería que tenga la tensión correcta, pueda entregar la corriente máxima requerida y proporcione una autonomía razonable, sin desarrollar un modelo eléctrico detallado del robot.

# 1. Datos mínimos a reunir

- Tensión de alimentación admisible de los servos y de la electrónica.

- Cantidad total de servos y cantidad máxima que pueden trabajar simultáneamente.

- Corriente de cada servo: usar, si está disponible, la corriente de bloqueo (stall) como referencia conservadora.

- Corriente aproximada de la electrónica adicional: ESP32, sensores, drivers, etc.

- Autonomía objetivo del robot (por ejemplo, 15–30 minutos de práctica).

# 2. Paso A — Seleccionar la tensión de la batería

La tensión de batería no se elige por autonomía sino por compatibilidad con los actuadores y la electrónica.

- Verificar la tensión nominal y máxima permitida por los servos.

- Si la batería entrega una tensión mayor que la admisible por los servos, usar un regulador/BEC adecuado.

- La tensión del sistema debe quedar dentro del rango permitido durante toda la descarga de la batería.

# 3. Paso B — Estimar la corriente máxima requerida

**Criterio rápido.** Sumar la corriente de los servos que podrían exigir esfuerzo al mismo tiempo y agregar la electrónica.

| **Robot** | **Estimación simplificada** | **Criterio recomendado** |
|:--:|----|----|
| **Cuadrúpedo** | Considerar los servos de las patas que están soportando el peso y los que se están moviendo. | Como preselección, considerar al menos 50–70 % de los servos trabajando simultáneamente. |
| **Segway con piernas extensibles** | Considerar los servos de ambas piernas y cualquier servo que sostenga o modifique la altura del cuerpo. | Como preselección, considerar todos los servos principales de las dos piernas trabajando simultáneamente. |

**Corriente de diseño:** I_diseño ≈ I_servos simultáneos + I_electrónica

**Margen recomendado:** seleccionar batería, BEC y cableado para al menos 1,5 veces la corriente estimada. Si no se dispone de buenos datos de corriente, usar un margen cercano a 2.

# 4. Paso C — Estimar la capacidad para la autonomía

Para una estimación rápida, usar una corriente media de funcionamiento. No conviene usar la corriente de bloqueo para calcular autonomía porque sería excesivamente conservadora.

**Capacidad mínima \[Ah\] ≈ Corriente media \[A\] × Tiempo de uso \[h\]**

**Capacidad seleccionada ≈ Capacidad mínima × 1,3 a 1,5**

Si no se conoce la corriente media, para una primera compra puede estimarse como 25–40 % de la corriente máxima calculada y luego medirla en el prototipo con un amperímetro o medidor de potencia.

# 5. Paso D — Verificar que la batería pueda entregar la corriente

- La corriente continua admisible de la batería debe ser mayor que la corriente de diseño.

- En baterías con especificación C: Corriente disponible ≈ Capacidad \[Ah\] × C.

- También verificar el límite de corriente del BEC/regulador, conectores y cables; una batería adecuada no compensa un regulador subdimensionado.

# 6. Regla práctica para la compra inicial

**Primero tensión, después corriente, finalmente capacidad.** La batería elegida debe cumplir simultáneamente las tres condiciones.

- Tensión compatible con servos/electrónica.

- Corriente disponible ≥ 1,5 × corriente máxima estimada.

- Capacidad ≥ 1,3–1,5 × la necesaria para la autonomía objetivo.

- Peso y tamaño compatibles con el robot. En robots pequeños, sobredimensionar demasiado la batería aumenta masa, torque requerido y consumo.

# 7. Validación posterior al armado

Esta metodología es de preselección. Una vez armado el robot, medir corriente pico, corriente media, caída de tensión y temperatura de batería/regulador. Con esos datos se corrige la selección definitiva.

**Importante:** no descargar ni cargar baterías de litio fuera de las especificaciones del fabricante. Utilizar cargador compatible, protección adecuada y supervisión durante las pruebas.

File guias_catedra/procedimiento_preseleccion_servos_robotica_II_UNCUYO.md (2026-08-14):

> **Objetivo.** Realizar una preselección rápida y conservadora del torque de los servos sin desarrollar todavía el modelo dinámico completo. Se usa un cálculo estático de peor caso y un factor de seguridad para cubrir movimientos lentos, aceleraciones, impactos y errores de estimación.

# A. Pasos comunes

1.  **Definir la postura crítica.** Elegir la configuración que genere el mayor brazo de palanca respecto del servo. Como criterio conservador, usar la pierna extendida o casi extendida.

2.  **Identificar la carga que actúa.** Determinar qué parte de la masa del robot debe sostener esa articulación en la postura crítica.

3.  **Convertir masa en fuerza.** Calcular la fuerza gravitatoria como F = m · g, usando g ≈ 9,81 m/s².

4.  **Calcular el torque estático.** Usar T = F · d, donde d es la distancia perpendicular desde el eje del servo hasta la línea de acción de la fuerza.

5.  **Aplicar margen.** Multiplicar el torque estático por un factor de seguridad entre 2 y 3. Para una compra preliminar, usar 2,5 como valor recomendado.

6.  **Seleccionar el servo.** Elegir un servo cuyo torque útil a la tensión real de alimentación sea igual o mayor que el torque requerido. Evitar comparar solamente con el “stall torque” si el fabricante también informa torque continuo o de operación.

# B. Criterio para cada robot

| **Robot** | **Carga simplificada** | **Postura / brazo** | **Torque preliminar** |
|:--:|----|----|:--:|
| **Cuadrúpedo** | Tomar, como peor caso simple, que una sola pierna soporta aproximadamente el 50 % de la masa total del robot. | Usar la pierna extendida y medir el brazo perpendicular desde cada articulación hasta la línea de acción de la reacción del piso. | Treq ≈ 2,5 · (0,5 · Mtotal · g) · d |
| **Segway con piernas extensibles** | Tomar la masa efectivamente sostenida por la articulación analizada. Si las dos piernas comparten simétricamente el peso, comenzar con ≈ 50 % de la masa soportada por pierna. | Usar la configuración de máxima extensión o la que produzca el mayor brazo entre el eje del servo y el centro de masa de la parte sostenida. | Treq ≈ 2,5 · (msoportada · g) · d |

# C. Interpretación de las fuerzas

**Cuadrúpedo.** La fuerza principal es la reacción vertical del piso. Para movimiento muy lento, su magnitud puede aproximarse con la fracción del peso que soporta la pierna. Esa fuerza genera momento en cadera, rodilla y demás articulaciones según su brazo de palanca.

**Segway.** La fuerza base también proviene del peso de la masa sostenida. La velocidad por sí sola no genera una fuerza adicional; lo que importa dinámicamente es la aceleración. Como no se realizará aún un modelo dinámico, sus efectos se absorben mediante el factor de seguridad. Si el sistema se mueve lentamente, esta aproximación es razonable para una preselección.

# D. Checklist de compra rápida

☐ Estimar masa total del robot y masa soportada por cada articulación.

☐ Dibujar la postura más desfavorable.

☐ Medir o estimar el brazo de palanca d.

☐ Calcular T = m · g · d.

☐ Multiplicar por 2,5.

☐ Comparar con el torque del servo a la tensión real de alimentación.

☐ Verificar además tensión, corriente pico, velocidad, rango angular, tamaño, masa y tipo de engranajes.

> **Importante:** este procedimiento sirve para preselección y compra inicial. Luego, con el prototipo disponible, conviene validar corriente, temperatura y margen de torque mediante ensayos, y eventualmente reemplazar esta aproximación por el modelo dinámico completo.

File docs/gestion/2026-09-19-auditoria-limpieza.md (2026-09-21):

# Auditoría de limpieza del repositorio (2026-09-19)

Objetivo: identificar todo lo que quedó obsoleto de propuestas anteriores y decidir qué borrar,
con un nivel de seguridad por ítem. **No se borró nada al hacer esta auditoría.** Todo lo que se
borre queda en la historia de git y se puede recuperar.

Cómo se hizo: `git log` por carpeta y primer commit de cada archivo, búsqueda de referencias
cruzadas (`grep` sobre `.m`, `.py`, `.tex`, `.md`), `md5sum` para duplicados, y parseo de los
STEP de la segunda iteración para medir el CAD sin SolidWorks. No se leyó ningún PDF.

## Resumen

1. Hay **dos problemas que van antes que la limpieza**: `modelado/dinamica/dinamica_pata.m`
   está commiteado con un conflicto de git sin resolver (no corre), y **el CAD de la segunda
   iteración no tiene las medidas del modelado** (barras a escala 80, modelado a escala 100).
2. Lo que es basura con seguridad alta pesa unos **190 MB** de los ~245 MB del working tree:
   el toolbox de Corke vendoreado (120 MB), un cuaderno OneNote (17 MB), el concepto anterior
   con motores N20 (29 MB), dos `.mat` regenerables (23 MB) y varios duplicados.
3. Lo que requiere decisión de Francisco es el CAD (piezas duplicadas por Pack and Go,
   tornillería en cuatro lugares, primera iteración). Lo que requiere decisión de equipo es
   `simulacion/planta_v2/`, que hoy sigue siendo el único modelo completo del robot.

## 1. Antes de limpiar

### 1.1 `dinamica_pata.m` está roto: conflicto de git commiteado

Qué pasó (según el reflog del 19/9):

| Hora | Acción | Resultado |
|---|---|---|
| 12:01:10 | GitHub Desktop hizo `stash` de tus cambios locales (commit `661c39f`) | tu `dinamica_pata.m` de 444 líneas quedó en el stash |
| 12:01:12 | `pull` fast-forward a `d1e1a8b` (commits de Matias del 14 y 15/9) | Matias había reescrito `dinamica_pata.m` como un demo de 70 líneas que llama a su API |
| 12:01 | GitHub Desktop reaplicó el stash | conflicto en `dinamica_pata.m` |
| 12:08:04 | commit `eca3ed4` | **se commiteó con los marcadores `<<<<<<<` adentro** |

Estado actual del archivo: 472 líneas, dos hunks de conflicto (líneas 1-69 y 116-471). La parte
"común" entre los hunks es código de Matias, así que el archivo mezcla su demo (que usa
`terminos_dinamica_pata`, `p.theta_min`, `p.Kp`) con las secciones 4 a 6 y las funciones locales
del script grande. Ninguna de las dos mitades es un archivo válido. Es el único archivo del repo
con marcadores.

La versión limpia existe: el stash descartado `661c39f` tiene el `dinamica_pata.m` de 444 líneas
con las seis secciones y sin marcadores; sus secciones 4 a 6 y funciones son idénticas a las que
quedaron en el conflicto. Recuperarla es `git show 661c39f:modelado/dinamica/dinamica_pata.m`.

Propuesta (5 minutos, no depende de nadie):

- restaurar `dinamica_pata.m` desde `661c39f`;
- guardar el demo de Matias (los 70 líneas de `d1e1a8b`) como `modelado/dinamica/demo_api_dinamica_pata.m`
  y corregir la línea que lo nombra en `modelado/dinamica/README.md`. El banco Simulink de Matias
  usa la API (`*_dinamica_pata.m`), no el script, así que no se rompe nada;
- avisarle a Matias.

Nota de fondo, que no es basura pero hay que decidir: desde el 14/9 hay **dos implementaciones de
la misma física** en `modelado/dinamica/`: las funciones locales `terminos`/`nucleo` del script
grande y la API de Matias (`terminos_dinamica_pata.m` y compañía, con tests). Y dos juegos de
parámetros que no coinciden:

| Parámetro | `dinamica_pata.m` sección 1 | `parametros_fisicos.m` (Matias) |
|---|---|---|
| Par máximo del servo | 21 kg·cm | 24,5 kg·cm (hoja a 6,8 V) |
| Kp / Kd del lazo interno | 30 / 0,5 | 45 / 1,0 |
| Fricción | `b_A, b_B, b_C, b_D` por pivote (todas 0) | un solo `b_servo` (0) |
| Caída de escalón, fuerza radial | sí | no |

`parametros_fisicos.m` ya es la fuente de la cinemática (`parametros_geometria.m` es un adaptador)
y de `planta_v2`. Lo razonable es que el script grande también lea de ahí. Es trabajo, no limpieza.

### 1.2 El CAD no tiene las medidas del modelado

Medido sobre los STEP que subió Francisco el 14/9 (`segunda_iteracion/completo/step/`): agujeros
de cada pieza más la posición de cada instancia en el ensamble. El cuatro barras cierra con
0,004 mm de error y las dos patas son idénticas, así que los números son confiables.

| Cota | Modelado (`corregido`, todo lo de `modelado/`) | **CAD segunda iteración** | `parametros_fisicos('cad')` (primera iteración) |
|---|---|---|---|
| AB (bancada) | 100 mm a 45° | **77,9 mm a 46,6°** | 80 mm a 47,5° |
| AD (manivela) | 140 | **112** | 140 |
| BC (balancín) | 135 | **108** | 135 |
| CD | 51 | **40,8** | 51 |
| DP | 140 | **112** | 140 |
| δ | 164° | 164,0° | 164° |
| Pose armada | — | θ = 40,2° (estirada), P 148 mm bajo A | θ ≈ 49° |
| Rueda, motor, tapa | Rw 33 mm, 95 g, 114 g | **no están en el ensamble** | sí |

Lectura: Francisco llevó las barras a la familia de escala 80 (1,40 / 1,35 / 0,51 / 1,40 × 80),
que era la segunda salida que proponía el informe de la primera iteración. El modelado tomó la
primera salida (AB a 100 mm a 45° con barras de escala 100). **Las dos ramas del equipo eligieron
opciones distintas de la misma bifurcación**, y ninguna de las dos variantes de
`parametros_fisicos.m` describe el CAD actual.

Detalle de la bancada: B está exactamente a 56,57 mm por encima de A (= 80 · sen 45°), pero a
53,50 mm en horizontal en vez de 56,57. Es decir, la intención era claramente 80 mm a 45° y **B
quedó 3 mm corto en horizontal**. Con la bancada fuera de familia el mecanismo pierde la línea
recta (el informe de la primera iteración lo cuantificó). Preguntarle a Francisco si es adrede.

Consecuencias:

- Todo número de `modelado/` (11,6 kg·cm estático, 131 mm de carrera, 18 cm de escalón,
  fuerzas en los pasadores, tabla de servos) está calculado para un robot 20 % más grande que el
  CAD. No está mal derivado, está derivado para otra geometría. A escala 80 la carrera es ~105 mm,
  el par estático ~9 kg·cm y el resto hay que volver a correrlo.
- Hay que elegir qué manda. Lo más probable es que mande el CAD, porque imprimir es lo caro.
  En ese caso el cambio es chico: `s_barras = 80` y `AB = 80` en `parametros_fisicos.m` (nueva
  variante `segunda_iteracion`), los cinco números al principio de `geometria_robot.py`,
  `fig_dinamica.py`, `fig_casos.py`, `fig_apoyado.py` y `dcl_pata.py`, las tablas de cotas en los
  cuatro `.tex`, y regenerar figuras y PDF. Una tarde.
- El ensamble de la segunda iteración no tiene rueda, motor ni tapa, así que la ficha de masas
  (CAD-201 del backlog) no se puede cerrar con este STEP solo. Los únicos datos de masa siguen
  siendo los de la primera iteración.

Los dos scripts de Python que miden los STEP (`step_agujeros.py`, `step_cuatro_barras.py`) están
en el scratchpad de la sesión; si sirven para CAD-201 se pueden agregar a `diseño_mecanico/`.

## 2. Qué borrar y con qué seguridad

Escala: **alta** = borrar, no hace falta preguntarle a nadie; **media** = borrar, pero avisar
al autor o decidir un detalle; **baja** = no borrar sin acuerdo del equipo.

### 2.1 Seguridad alta

| # | Ruta | Qué es | Quién / cuándo | Tamaño | Por qué es basura |
|---|---|---|---|---|---|
| A1 | `modelado/cinematica/rtb/`, `smtb/`, `common/` | Robotics Toolbox y Spatial Math Toolbox de Peter Corke, copiados enteros al repo (demos, manuales, mallas de robots industriales, Octave) | Francisco, 2/9 (`73d2a47`) | **120 MB, ~940 archivos** (95 % de los archivos del repo) | Es una librería de terceros; se instala, no se versiona. Solo la usa opcionalmente `verificar_cinematica_4barras.m`, que tiene doble guarda (`if exist(rtb)` y `if exist('SerialLink')`) y sin ella imprime un aviso y sigue. Borrar no rompe nada. |
| A2 | `modelado/cinematica/modelado/New Section 1.one` + `Open Notebook.onetoc2` | Cuaderno de OneNote | Francisco, 2/9 (80 KB); creció a **17 MB** en tu commit `1d9eac9` del 13/9 | 17 MB | Apuntes personales en binario; git no puede hacer diff ni merge. Lo que sirva se exporta a `.md`. Confirmar de quién es antes. |
| A3 | `modelado/dinamica/fig/` | 7 PNG | apareció en tu stash, commiteado hoy (`eca3ed4`) | 690 KB | Byte a byte idénticos a `docs/informe_planta_v1/fig/`; nada en `modelado/` los referencia. |
| A4 | `diseño_mecanico/proof_of_concept/` | Motores N20, microservo SG90, trenes de engranajes 10T/34T, "eslabón fémur", "pantorrilla flexible" | Francisco, 16/8 a 1/9 | **29 MB**, 31 archivos | Es el concepto anterior al cuatro barras (motores chicos, pierna flexible). Nada lo referencia. |
| A5 | `diseño_mecanico/4_bar_mechanism/` | Primer boceto del cuatro barras, piezas `link_0` a `link_5` | Francisco, 31/8 | 650 KB | Superado por `primera_iteracion` un día después. |
| A6 | `diseño_mecanico/4 barras.motiongen` | Síntesis en MotionGen | Francisco, 27/8 | 4 KB | Del primer concepto. |
| A7 | `simulacion/hoekens_dh.html` | Página "Mecanismo Hoeken y parámetros DH" | Francisco, 27/8 | 21 KB | El Hoeken se descartó por el cuatro barras `grupo`; DH no aplica. |
| A8 | 18 archivos `~$*.SLDPRT` / `~$*.SLDASM` en `segunda_iteracion/`, `completo/`, `utilidades/` | Archivos de bloqueo de SolidWorks (10 bytes cada uno) | Francisco, 14/9 | 0 | Se crean al abrir una pieza; nunca deben versionarse. Agregar `~$*` al `.gitignore`. |
| A9 | `diseño_mecanico/utilidades/ds3225-mg-metal-horn-1.snapshot.4.zip` | Zip del horn del servo | Francisco, 10/9 | 1,2 MB | Su contenido ya está descomprimido en la carpeta de al lado (y además copiado en `segunda_iteracion/`). |
| A10 | `simulacion/planta_v2/resultados/*.mat` (2 archivos) | Salidas crudas de simulación | Joaquín, 3/9 | **23 MB** | Se regeneran con `correr_escenarios_robot` en un minuto. Conservar los `.md` de resumen. |
| A11 | `docs/informe_planta_v1/informe.tex` | Fuente LaTeX de `cinematica_dinamica_segway.pdf` | Joaquín, 3/9 | 26 KB | Ese PDF lo borraste el 13/9 (`1d9eac9`); la fuente quedó huérfana. `manual_modelo.tex` la reemplazó. |
| A12 | `docs/superpowers/plans/2026-09-02-planta-simulink-v1.md` y `specs/2026-09-02-planta-simulink-v1-design.md` | Plan y diseño de `planta_v1` | Joaquín, 3/9 | 81 KB | `planta_v1` se borró el 13/9. |
| A13 | `.codebase-memory/` | Caché de un indexador de código (`artifact.json`: indexado el 27/8 sobre el commit `be546a2`, 29 nodos) | Francisco, 27/8 | 14 KB | Caché de herramienta, rancio desde el segundo commit. Agregar al `.gitignore`. |
| A14 | `docs/diagramas/flujo_agente_svgbob.*` | Diagrama "Agente → .bob → svgbob → SVG" | Francisco, 5/9 | 20 KB | Es una demo de la herramienta de diagramas, no contenido del proyecto. Avisarle. |
| A15 | `.gitkeep` en `base_conocimiento/`, `diseño_mecanico/`, `simulacion/` | Placeholders | Francisco, 27/8 | 0 | Las carpetas ya tienen contenido. |

### 2.2 Seguridad media

| # | Ruta | Qué es | Por qué dudar | Propuesta |
|---|---|---|---|---|
| M1 | `diseño_mecanico/primera_iteracion/` (12 MB) | CAD de la primera iteración: AB 80 a 47,5°, barras a escala 100 | Superada, pero `completo.STEP` es el **único STEP con rueda, motor y tapa** y es la fuente de `base_conocimiento/dimensiones_cad_primera_iteracion.md` y de todas las masas e inercias de `parametros_fisicos.m`. Y `mass_properties.md` es la salida de SolidWorks de Francisco (587,7 g de ensamble; no coincide con los 802 g estimados por volumen, vale revisarlo). | Borrar los `.SLDPRT`/`.SLDASM` (están en la historia). Mover `completo.STEP` y `mass_properties.md` a `base_conocimiento/` hasta cerrar CAD-201. |
| M2 | `segunda_iteracion/` vs `segunda_iteracion/completo/` | 19 piezas duplicadas: `completo/` es un Pack and Go (prefijo `asml_`, sufijo `v4`) del padre. Además dos pares de ensambles: `completo_v2/v3.SLDASM` y `asml_completo_v2v4/v3v4.SLDASM` | Las piezas del padre son más nuevas (Francisco las editó el 14/9 después del Pack and Go), pero el ensamble que editó y del que salieron los STEP es el de `completo/`. Sin SolidWorks no se puede saber cuál juego referencia el ensamble maestro. | **Francisco** elige un juego de piezas y un ensamble (v2 o v3) y borra el resto. Debería quedar una sola carpeta `segunda_iteracion/` con piezas, ensamble y `step/`. |
| M3 | Tornillería y compras en cuatro lugares | Tuercas, tornillos, arandelas, servo y horn están en `utilidades/` (`.SLDPRT` + `.step`), en `segunda_iteracion/`, en `segunda_iteracion/completo/` y en `completo/step/` | SolidWorks referencia por ruta; borrar la copia equivocada rompe el ensamble. | **Francisco**: una sola biblioteca de compras (`utilidades/` o dentro de `segunda_iteracion/`). |
| M4 | `utilidades/JGA25-370 DC 12V60RPM.SLDPRT` (+ copia en `primera_iteracion/`) | Motor de 60 rpm | La simulación mostró que con 60 rpm el robot no baja escalones; `corregido` usa 280 rpm. | Borrar si el motor ya está decidido. |
| M5 | `simulacion/simular_pata_segway.m`, `optimizar_barrido_local.m` | GUI con sliders y barrido de fuerza bruta que produjeron las proporciones 1,40 / 1,35 / 0,51 / 1,40 / 164° | Francisco, 28/8. Cumplieron su función; no los usa nada. Pero son el registro de cómo salieron las proporciones. | Moverlos a `modelado/geometria/sintesis/` o borrar (quedan en la historia). |
| M6 | `modelado/cinematica/geometrico_1.jpeg`, `geometrico_2.jpeg` | Fotos de pizarra | Francisco, 2/9. Nada las referencia; la deducción ya está en `cinematica_resumen.pdf`. | Borrar si el grupo confirma que no las necesita. |
| M7 | `modelado/cinematica/verificar_cinematica_4barras.m`, `graficar_robot_corke.m` | Verificación de la cinemática de tus compañeros con Corke | Sigue funcionando sin Corke (avisa y omite esa parte). | Conservar; borrar solo si el grupo no lo usa. |
| M8 | `docs/superpowers/specs/2026-09-03-planta-v2-escalones-design.md`, `2026-09-03-simulink-bloques-design.md` | Diseño de `planta_v2` y del Simulink por bloques | Van atados a `planta_v2` (ver B1). | Se van con `planta_v2`. |
| M9 | `docs/informe_planta_v1/manual_modelo.tex` + `fig/`, `docs/manual_modelo_segway.pdf` | Manual del modelo de `planta_v2` (lo referencia su README) | Idem. | Se van con `planta_v2`. |
| M10 | `.omp/` | Config de oh-my-pi: un MCP de SolidWorks con rutas de la máquina de Francisco (`C:/Users/caste/...`) y una skill `solidpilot` | Es config personal; no funciona en otra PC. 29 KB, no molesta. | **Francisco** decide; iría en su usuario, no en el repo. |
| M11 | `base_conocimiento/ResumenDH.pdf` | Resumen de Denavit-Hartenberg | De la etapa de robot serie; el cuatro barras no usa DH. | Mover a `referencias/` (está vacía) o borrar. |
| M12 | `parametros_fisicos.m`, variante `'cad'` | Describe la **primera** iteración (AB 80 a 47,5°, barras 100, motor 60 rpm) | Ya no existe ese CAD. | Reemplazar por la segunda iteración real cuando se resuelva 1.2. |

### 2.3 Seguridad baja: no borrar sin acuerdo del equipo

| # | Ruta | Por qué no |
|---|---|---|
| B1 | `simulacion/planta_v2/` (37 archivos + tests + 26 PNG de diagramas) | Es el único modelo completo del robot (péndulo, ruedas, motores, contacto, sensores, LQR) y pasa 21/22 tests. El plan de Matias (PLT-303) lo usa como baseline, `test_dinamica_pata.m` importa `parametros_robot` de ahí, y su `parametros_editables.m` ya lee de `parametros_fisicos.m`. Vos querés rehacer la planta a mano en `modelado/planta/`. Propuesta: conservarlo hasta que `modelado/planta/` lo reemplace, y ese día borrar `planta_v2` + M8 + M9 juntos. |
| B2 | `simulacion/dinamica_pata_v1/` | Trabajo vigente de Matias (14 y 15/9): banco Simulink de la pata, 12/12 tests, con punto de entrada `INICIAR_DINAMICA_PATA.m`. Su física es la de `c5602f1` (sin la fricción por pivote ni la caída de escalón). |
| B3 | `modelado/dinamica/*_dinamica_pata.m`, `tests/`, `modelado/parametros/` | La API de Matias que alimenta B2. Ver 1.1. |
| B4 | `docs/gestion/` | Plan, guía de QA, traspaso y entorno MCP de Matias. Vigentes. |
| B5 | `base_conocimiento/Segway-Pata-Dimensionamiento.docx` | El documento original de dimensionamiento (Hoeken, flexor, objetivo 800 g). Es la fuente del `k_flexor`. Conservar, o mover a `referencias/`. |

## 3. Cuánto se ahorra

| | Hoy | Después de 2.1 | Después de 2.1 + M1 a M4 |
|---|---|---|---|
| `modelado/` | 141 MB | ~4 MB | ~4 MB |
| `diseño_mecanico/` | 68 MB | ~37 MB | ~20 MB |
| `simulacion/` | 32 MB | ~9 MB | ~9 MB |
| Working tree | ~245 MB | ~55 MB | ~38 MB |

El `.git/` (127 MB, 61 MB empaquetado) no cambia al borrar archivos: la historia conserva todo.
Reescribir la historia con `git filter-repo` lo bajaría a unos 15 MB, pero en un repo compartido
por tres obliga a que todos vuelvan a clonar el mismo día. No lo recomiendo salvo que se haga una
sola vez y coordinado.

## 4. No es basura, pero está desactualizado

- `README.md` de la raíz: la lista de carpetas no menciona `modelado/` ni `docs/`.
- `modelado/README.md`: no menciona `parametros/` ni la API y los tests de Matias en `dinamica/`.
- `.gitignore`: falta `~$*` (locks de SolidWorks), `*.one`, `*.onetoc2`, `.codebase-memory/`, y
  probablemente `simulacion/**/resultados/*.mat`.
- `BACKLOG.md`, CAD-201: sigue "bloqueado"; ahora hay cotas medidas (sección 1.2).
- `geometria_robot.py` y `cinematica_resumen.tex` dicen "según el CAD primera_iteracion" con
  AB = 100: nunca fue así en ningún CAD (la primera tenía 80 a 47,5°). Corregir el texto cuando
  se resuelva 1.2.

## 5. Orden propuesto

1. Hoy, sin preguntarle a nadie: arreglar `dinamica_pata.m` (1.1) y borrar la lista 2.1.
   Un commit "limpieza" por separado del arreglo.
2. Mandarle a Francisco: la tabla 1.2 (qué geometría manda, y los 3 mm de B), y M1 a M4, M6, M10.
3. Mandarle a Matias: 1.1 (el demo renombrado y la fuente única de parámetros).
4. Cuando exista `modelado/planta/`: B1 + M8 + M9.

## 6. Ejecución (misma tarde del 19/9)

Joaquín decidió ir más lejos que la lista 2.1: borrar todo lo anterior al cuatro barras, `planta_v2` incluida,
dejar solo el banco de Matías en `simulacion/`, y pasar el modelado a escala 80 siguiendo el CAD.

- Hecho: 1.1 (conflicto resuelto desde `661c39f`; el demo de Matías quedó en `demo_api_dinamica_pata.m`); todo 2.1;
  M1 (quedan `completo.STEP` y `mass_properties.md`), M4, M5, M6, M8, M9, M11, B1, B5 (la `.docx` era del Hoeken).
- Hecho además: `parametros_fisicos.m` con la variante `segunda_iteracion` por defecto (escala 80, servo de 40 kg·cm,
  motor JGB37-520 de 152 g); las 7 figuras, los 4 PDF y `dinamica_pata.m` a esa geometría; tests 8/8 y Simulink 4/4;
  README raíz y de cada carpeta reescritos; `diseño_mecanico/medir_step/` con los scripts que miden los STEP.
- Pendiente de Joaquín: `git rm -r simulacion/planta_v2` (el agente no tiene permiso para borrar esa carpeta).
- Pendiente de Francisco: M2, M3, M10 y los 3 mm de B (ver `diseño_mecanico/README.md`).

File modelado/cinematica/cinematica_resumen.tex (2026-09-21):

\documentclass[11pt,a4paper]{article}
\usepackage[utf8]{inputenc}
\usepackage[T1]{fontenc}
\usepackage[spanish,es-noshorthands]{babel}
\usepackage[margin=2.2cm]{geometry}
\usepackage{amsmath,amssymb,bm}
\usepackage{graphicx}
\usepackage{booktabs}
\usepackage{xcolor}
\usepackage{enumitem}
\usepackage[colorlinks=true,linkcolor=blue!50!black,urlcolor=blue!50!black]{hyperref}
\graphicspath{{./}{../}}
\setlength{\parskip}{4pt}
\setlength{\parindent}{0pt}
\newcommand{\atan}{\operatorname{atan2}}
\title{Cinemática de la pata del Segway: resumen de los cálculos\\
\large Mecanismo de cuatro barras \(A\,B\,C\,D\) con acoplador rígido \(C\,D\,P\)}
\author{Proyecto Segway con patas -- Robótica II, UNCUYO}
\date{\today}

\begin{document}
\maketitle

\section{Geometría y notación}

Todo se mide en el plano lateral del robot, con origen en \(A\) (eje del servo), \(x\) positivo hacia
atrás e \(y\) positivo hacia arriba. Los segmentos se nombran por sus extremos; los ángulos son
antihorarios desde \(+x\).

\begin{center}
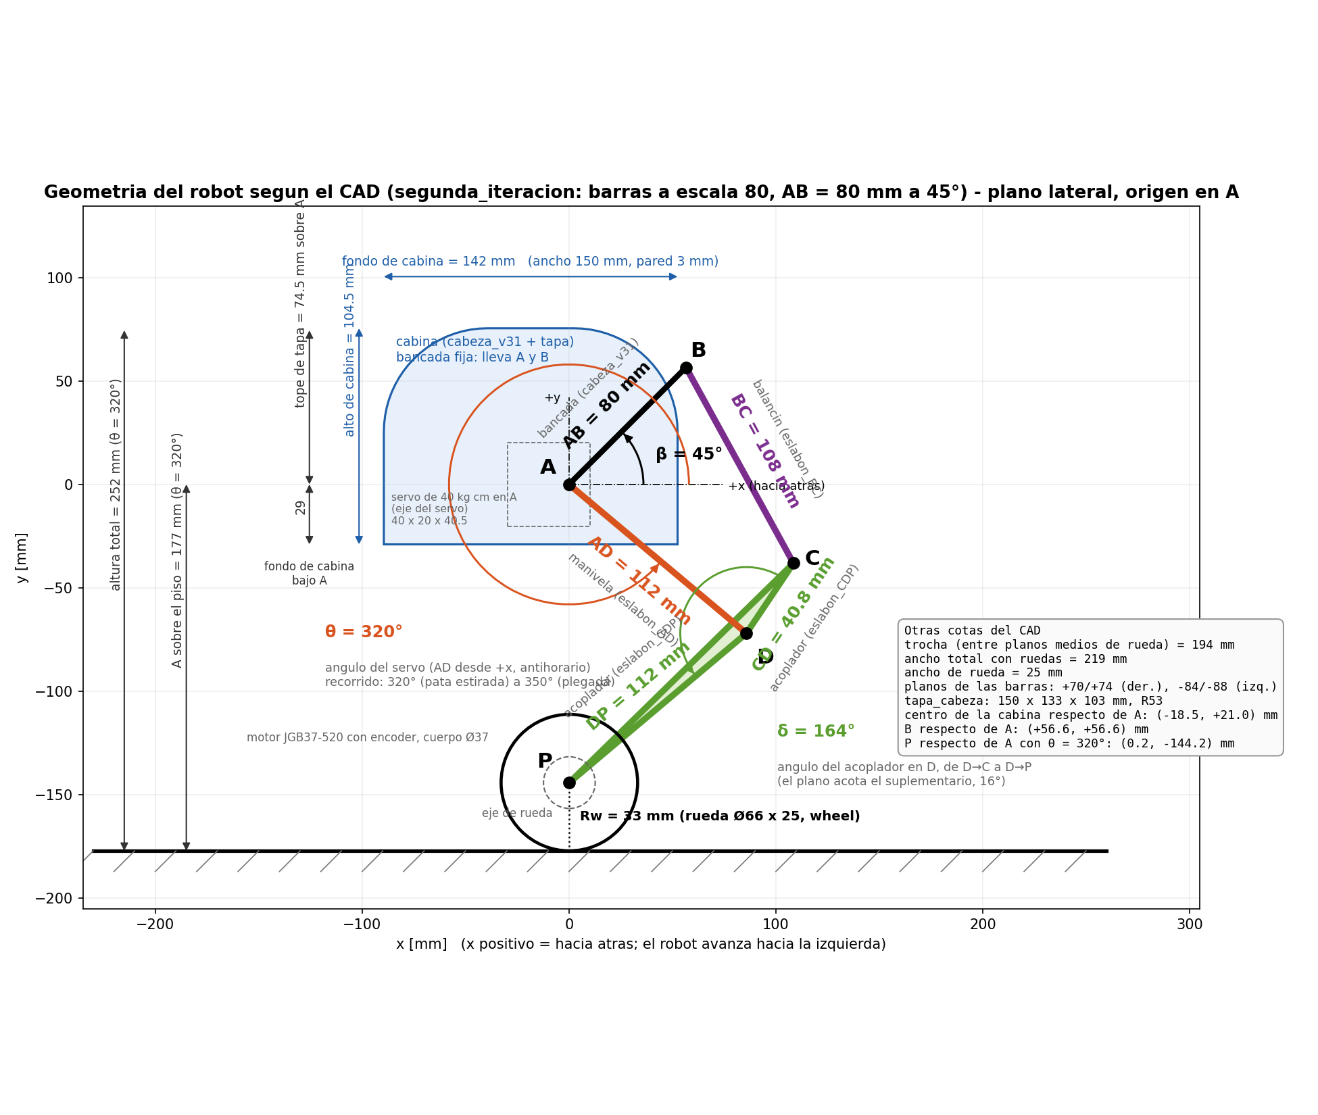
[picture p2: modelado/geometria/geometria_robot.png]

\end{center}

\begin{center}
\small
\begin{tabular}{llcl}
\toprule
Símbolo & Qué es & Valor CAD & Pieza \\
\midrule
\(AB\) & bancada: distancia entre los pivotes \(A\) y \(B\) de la cabina & 80 mm & \texttt{cabeza\_v31} \\
\(\beta\) & ángulo de \(A\!\to\!B\) desde \(+x\) & \(45^\circ\) & \texttt{cabeza\_v31} \\
\(AD\) & manivela (la mueve el servo) & 112 mm & \texttt{eslabon\_AD\_v2} \\
\(BC\) & balancín & 108 mm & \texttt{eslabon\_BC} \\
\(CD\) & acoplador, tramo \(C\)--\(D\) & 40.8 mm & \texttt{eslabon\_CDP\_v2} \\
\(DP\) & acoplador, tramo \(D\)--\(P\) (hasta el eje de rueda) & 112 mm & \texttt{eslabon\_CDP\_v2} \\
\(\delta\) & ángulo del acoplador en \(D\), de \(D\!\to\!C\) a \(D\!\to\!P\) & \(164^\circ\) (plano: \(16^\circ\)) & \texttt{eslabon\_CDP} \\
\(\theta\) & ángulo del servo: dirección de \(A\!\to\!D\) desde \(+x\) & \(320^\circ\) a \(350^\circ\) & servo en \(A\) \\
\(R_w\) & radio de rueda & 33 mm & \texttt{wheel} \\
\bottomrule
\end{tabular}
\end{center}

Cotas de la segunda iteración del CAD (\texttt{diseño\_mecanico/segunda\_iteracion}, STEP del 14/9/2026), medidas sobre
los STEP de cada pieza y del ensamble. La bancada se toma como 80 mm a \(45^\circ\), que es la intención del diseño; en
el STEP \(B\) está a 77.9 mm y \(46.6^\circ\) de \(A\) (a la altura justa, 3 mm corto en horizontal), pendiente de corregir.

Variables intermedias que aparecen en la deducción: \(BD\) (diagonal), \(\alpha_{DB}\) (dirección de
\(D\!\to\!B\)), \(\gamma\) (ángulo en \(D\) del triángulo \(BDC\)), \(\theta_{DC}\), \(\theta_{DP}\)
(direcciones de \(D\!\to\!C\) y \(D\!\to\!P\)), \(\theta_{BC}\) (dirección del balancín) y \(\mu\)
(ángulo de transmisión en \(C\)). La entrada es \(\theta\); la salida que interesa es la posición del
eje de rueda \(P=(x_P,\,y_P)\).

\section{Cinemática directa: de \(\theta\) a \(P\)}

\begin{center}
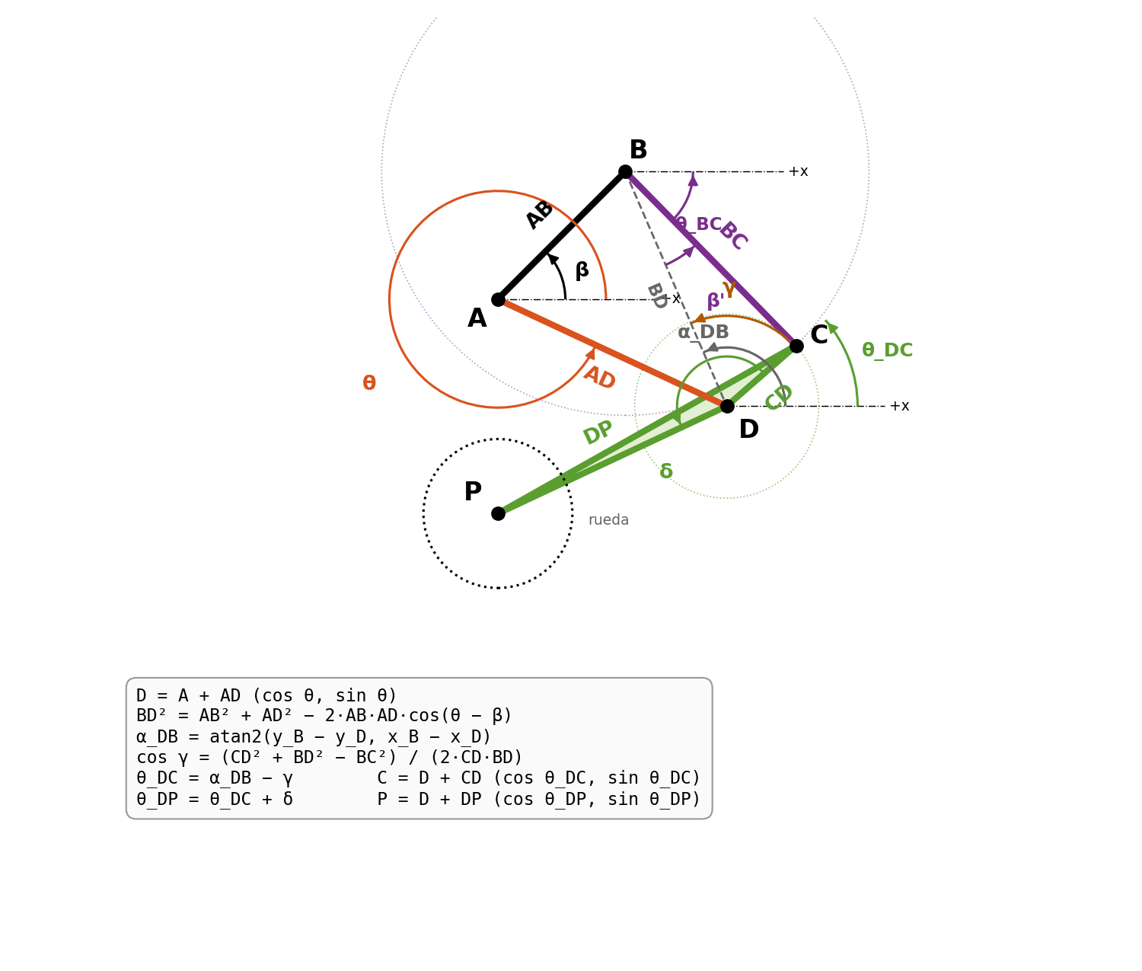
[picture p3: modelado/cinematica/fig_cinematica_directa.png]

\end{center}

\textbf{Datos fijos.} \(A=(0,0)\) y \(B=(x_B,y_B)=(AB\cos\beta,\;AB\sin\beta)\).

\textbf{Paso 1: la manivela.} El servo fija la dirección de \(A\!\to\!D\):
\begin{equation}
D=(x_D,y_D)=\bigl(AD\cos\theta,\;AD\sin\theta\bigr).
\end{equation}

\textbf{Paso 2: la diagonal \(BD\).} Es el lado del triángulo \(ABD\) opuesto al ángulo
\(\theta-\beta\) en \(A\); por la ley del coseno,
\begin{equation}
BD^2=AB^2+AD^2-2\,AB\,AD\cos(\theta-\beta),
\qquad
\alpha_{DB}=\atan\!\bigl(y_B-y_D,\;x_B-x_D\bigr).
\label{eq:BD}
\end{equation}

\textbf{Paso 3: el ángulo \(\gamma\) en \(D\).} En el triángulo \(BDC\) se conocen los tres lados
(\(BD\), \(CD\), \(BC\)); la ley del coseno da el ángulo en \(D\), entre \(D\!\to\!B\) y \(D\!\to\!C\):
\begin{equation}
\cos\gamma=\frac{CD^2+BD^2-BC^2}{2\,CD\,BD}.
\label{eq:gamma}
\end{equation}
El mecanismo cierra sólo si \(|BC-CD|\le BD\le BC+CD\) (equivale a \(|\cos\gamma|\le1\)). Es la
misma cuenta que intersecar la circunferencia de centro \(B\) y radio \(BC\) con la de centro \(D\) y
radio \(CD\).

\textbf{Paso 4: el punto \(C\).} Las dos intersecciones son \(\theta_{DC}=\alpha_{DB}\pm\gamma\). El CAD
está armado con \(C\) a la derecha de \(D\!\to\!B\) (\(C\) queda atrás y arriba de \(D\)), que es el
signo menos:
\begin{equation}
\theta_{DC}=\alpha_{DB}-\gamma,\qquad
C=\bigl(x_D+CD\cos\theta_{DC},\;y_D+CD\sin\theta_{DC}\bigr).
\end{equation}
La otra rama (\(\alpha_{DB}+\gamma\)) es la configuración cruzada del cuatro barras y no se usa.
Con el mismo criterio, visto desde \(B\): \(\theta_{BC}=\alpha_{BD}+\beta'\), con
\(\cos\beta'=(BC^2+BD^2-CD^2)/(2\,BC\,BD)\) y \(\alpha_{BD}=\alpha_{DB}+180^\circ\).

\textbf{Paso 5: el punto \(P\).} El acoplador es rígido: la dirección de \(D\!\to\!P\) está a \(\delta\)
de la de \(D\!\to\!C\):
\begin{equation}
\theta_{DP}=\theta_{DC}+\delta,\qquad
P=\bigl(x_D+DP\cos\theta_{DP},\;y_D+DP\sin\theta_{DP}\bigr).
\end{equation}

\subsection*{Ecuación final}

Reemplazando los pasos anteriores, la posición del eje de rueda en función del ángulo del servo es
\begin{equation}
\boxed{\;
\begin{aligned}
x_P(\theta)&=AD\cos\theta+DP\cos\bigl(\alpha_{DB}(\theta)-\gamma(\theta)+\delta\bigr),\\[2pt]
y_P(\theta)&=AD\sin\theta+DP\sin\bigl(\alpha_{DB}(\theta)-\gamma(\theta)+\delta\bigr),
\end{aligned}\;}
\label{eq:final}
\end{equation}
con
\begin{gather}
BD(\theta)=\sqrt{AB^2+AD^2-2\,AB\,AD\cos(\theta-\beta)},\qquad
\gamma(\theta)=\arccos\frac{CD^2+BD(\theta)^2-BC^2}{2\,CD\,BD(\theta)},\\[2pt]
\alpha_{DB}(\theta)=\atan\!\bigl(AB\sin\beta-AD\sin\theta,\;AB\cos\beta-AD\cos\theta\bigr).
\end{gather}
La altura del eje del servo sobre el piso es \(z_A=R_w-y_P(\theta)\), y la altura del eje de rueda
sobre el piso es \(R_w\).

\section{Cinemática inversa: de una altura a \(\theta\)}

Dada la altura deseada \(y_P^{*}\) hay que resolver \(y_P(\theta)=y_P^{*}\). La ecuación es
trascendente en \(\theta\) (aparecen \(\theta\) dentro de \(\arccos\) y de \(\atan\)) y no tiene
solución cerrada útil. En el recorrido del servo \(y_P(\theta)\) es monótona creciente (tabla de la
sección~\ref{sec:num}), así que la solución es única y se obtiene por bisección o con una tabla
\(\theta\leftrightarrow y_P\) interpolada. Eso hace \texttt{cinematica\_inversa.m}.

\section{Verificación numérica}\label{sec:num}

Con los valores del CAD, ecuación~\eqref{eq:final} evaluada en tres puntos del recorrido (mm y grados):

\begin{center}
\small
\begin{tabular}{ccccccccc}
\toprule
\(\theta\) & \(BD\) & \(\alpha_{DB}\) & \(\gamma\) & \(\theta_{DC}\) & \(D\) & \(C\) & \(P\) & \(z_A\) \\
\midrule
320 & 131.8 & 102.8 & 46.7 & 56.1 & (85.8, \(-72.0\)) & (108.5, \(-38.1\)) & (0.2, \(-144.2\)) & 177.2 \\
335 & 113.2 & 113.4 & 72.3 & 41.1 & (101.5, \(-47.3\)) & (132.2, \(-20.5\)) & (0.1, \(-94.9\)) & 127.9 \\
350 & 93.1 & 125.3 & 100.1 & 25.1 & (110.3, \(-19.4\)) & (147.2, \(-2.1\)) & (\(-0.3\), \(-37.2\)) & 70.2 \\
\bottomrule
\end{tabular}
\end{center}

\begin{itemize}[nosep]
\item Las longitudes \(|AD|,|BC|,|CD|,|DP|\) recalculadas desde los puntos coinciden con las cotas con
error menor que \(10^{-12}\) mm, y la ecuación~\eqref{eq:final} coincide con la construcción por
intersección de circunferencias del script del grupo con error menor que \(10^{-12}\) mm.
\item En todo el recorrido \(BD\in[93,\,132]\) mm, dentro de \([\,|BC-CD|,\,BC+CD\,]=[67,\,149]\) mm:
el mecanismo cierra siempre. El ángulo de transmisión en \(C\) va de \(63^\circ\) a \(58^\circ\)
(mayor que \(40^\circ\): sin riesgo de trabarse).
\item Carrera del eje de rueda entre \(320^\circ\) y \(350^\circ\): \(107.0\) mm vertical, con un desvío
horizontal de sólo \(0.5\) mm. Con la bancada a escala con las barras (\(AB=80\) mm a \(45^\circ\)) el mecanismo
hace la línea recta para la que fue diseñado (en la primera iteración, con barras de escala 100 y bancada de
80 mm a \(47.5^\circ\), el desvío era de 9 mm).
\end{itemize}

\section{Revisión de la cinemática que estaba en \texttt{modelado/cinematica}}

\begin{enumerate}[nosep]
\item \textbf{Las ecuaciones estaban bien.} Las hojas manuscritas y \texttt{verificar\_cinematica\_4barras.m}
hacen exactamente los pasos 1 a 5 (ley del coseno + intersección de circunferencias). Sólo se
reordenaron con un nombre por segmento (\(AB\), \(AD\), \(BC\), \(CD\), \(DP\)) y las cotas en un único
archivo, \texttt{parametros\_geometria.m}.
\item \textbf{Bancada.} En las hojas \(B=(L,0)\); en el CAD \(B=AB(\cos\beta,\sin\beta)\) con
\(\beta=45^\circ\). El script ya usaba \(45^\circ\); las hojas no.
\item \textbf{Signo de la rama.} Las hojas dejan \(\theta_{BC}=\alpha_{BD}\pm\beta'\) sin decidir. Para
la configuración del CAD es \(\theta_{DC}=\alpha_{DB}-\gamma\) (equivalentemente
\(\theta_{BC}=\alpha_{BD}+\beta'\)). La otra rama lleva \(P\) a \((204,\,-192)\) mm con
\(\theta=320^\circ\): la pata cruzada.
\item \textbf{Ángulo \(\delta\).} Las hojas escriben \(P=D-DP\,(\cos(\theta_{DC}-16^\circ),\,\sin(\theta_{DC}-16^\circ))\);
es lo mismo que \(\theta_{DP}=\theta_{DC}+164^\circ\) (el signo menos es el giro de \(180^\circ\)).
Conviene usar una sola forma: \(\delta=164^\circ\) antihorario desde \(D\!\to\!C\).
\item \textbf{Nombres.} En las hojas aparecen \(L_{CP}=1{,}4L\) y \(L_{DP}\) para el mismo tramo, y
\(L_{DC}\)/\(L_{CD}\); quedó \(DP\) y \(CD\).
\item \textbf{Unidades.} El script trabajaba en cm con \(L=10\); ahora todo está en mm con las cotas
reales del CAD y el radio de rueda de 33 mm (antes 37,5 mm).
\end{enumerate}

\subsection*{Archivos}
\begin{itemize}[nosep]
\item \texttt{modelado/geometria/geometria\_robot.png} (y \texttt{.py}): figura de la geometría con nombres y valores.
\item \texttt{modelado/cinematica/parametros\_geometria.m}: las cotas, leídas de \texttt{modelado/parametros/parametros\_fisicos.m} (la única fuente).
\item \texttt{modelado/cinematica/cinematica\_directa.m}: ecuaciones \eqref{eq:BD} a \eqref{eq:final}.
\item \texttt{modelado/cinematica/cinematica\_inversa.m}: \(\theta\) para una altura dada (bisección).
\item \texttt{modelado/cinematica/verificar\_cinematica\_4barras.m}: la animación del grupo, usando lo anterior.
\end{itemize}

\end{document}

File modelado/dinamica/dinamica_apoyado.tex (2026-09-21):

\documentclass[11pt,a4paper]{article}
\usepackage[utf8]{inputenc}
\usepackage[T1]{fontenc}
\usepackage[spanish,es-noshorthands]{babel}
\usepackage[margin=2.2cm]{geometry}
\usepackage{amsmath,amssymb}
\usepackage{graphicx}
\usepackage{booktabs}
\usepackage{longtable}
\usepackage{xcolor}
\usepackage{pdflscape}
\usepackage[colorlinks=true,linkcolor=blue!50!black,urlcolor=blue!50!black]{hyperref}
\setlength{\parskip}{5pt}
\setlength{\parindent}{0pt}
\newcommand{\dd}{\mathrm{d}}
\title{Dinámica de la pata con el robot apoyado\\
\large El caso que sirve para saber qué par pedirle al servo}
\author{Proyecto Segway con patas -- Robótica II, UNCUYO}
\date{\today}

\begin{document}
\maketitle

\section{Qué se plantea acá}

El robot está de pie sobre sus dos ruedas. El servo gira la manivela y, como la rueda apoya en el piso y no
se puede mover, lo que sube y baja es la cabina. Este es el caso que hay que resolver para saber qué par
necesita el servo: es el que tiene la masa de verdad, porque la cabina pesa casi cuatro veces más que la rueda.

Hay un solo grado de libertad, \(\theta\) (el ángulo del servo), y el camino es el de siempre: ángulos,
posiciones, velocidades, \(K\), \(U\), Lagrange. Lo que hay que mirar con cuidado es el paso de las
velocidades, porque ahí es donde entra que la rueda está quieta.

Se supone que el control de equilibrio mantiene el robot derecho mientras la pata se mueve, que las dos patas
se mueven juntas, y que la rueda no despega. Todo se escribe \textbf{por servo}: la energía del robot dividida
entre los dos.

\section{Las letras}

{\small\setlength{\tabcolsep}{5pt}
\begin{longtable}{l p{11.4cm}}
\toprule
\multicolumn{2}{l}{\textbf{La incógnita}}\\
\midrule
\(\theta\) & ángulo de la manivela \(AD\) por debajo de la horizontal. Es la coordenada generalizada, la única.
  \(10^\circ\) con la pata plegada, \(40^\circ\) estirada \\
\(\dot\theta,\;\ddot\theta\) & su velocidad y su aceleración, o sea cuán rápido y con qué aceleración gira el servo \\
\midrule
\multicolumn{2}{l}{\textbf{Las barras} (datos fijos del CAD)}\\
\midrule
\(AB\) & bancada, del eje del servo \(A\) al pivote \(B\). 80 mm, inclinada \(45^\circ\) \\
\(AD\) & manivela, la que mueve el servo. 112 mm \\
\(BC\) & balancín. 108 mm \\
\(CD\) & lado del acoplador que va a \(C\). 40.8 mm \\
\(DP\) & lado del acoplador que va al eje de la rueda \(P\). 112 mm \\
\(\delta\) & ángulo del acoplador en \(D\), entre \(DC\) y \(DP\). \(164^\circ\) \\
\(R_w\) & radio de la rueda. 33 mm \\
\midrule
\multicolumn{2}{l}{\textbf{Los ángulos que salen de \(\theta\)} (sección 3)}\\
\midrule
\(BD\) & diagonal del cuadrilátero, de \(B\) a \(D\). Cambia con \(\theta\) \\
\(\beta_1,\;\beta_2\) & ángulos en \(B\): \(\beta_1=\angle ABD\) y \(\beta_2=\angle DBC\) \\
\(\beta\) & ángulo interior del balancín en \(B\), \(\beta=\beta_1+\beta_2\) \\
\(\alpha_1,\;\alpha_2\) & ángulos en \(D\): \(\alpha_1=\angle ADB\) y \(\alpha_2=\angle BDC\) \\
\(\psi\) & giro del acoplador, medido desde la horizontal hasta la dirección \(D\!\to\!C\) \\
\(\beta',\;\psi'\) & cuánto giran el balancín y el acoplador por cada radián del servo: \(\beta'=\dd\beta/\dd\theta\),
  \(\psi'=\dd\psi/\dd\theta\) \\
\midrule
\multicolumn{2}{l}{\textbf{Las alturas} (sección 4)}\\
\midrule
\(y_P\) & altura del eje de la rueda \(P\) respecto de \(A\). Es negativa, porque \(P\) está abajo \\
\(y_P'\) & \(\dd y_P/\dd\theta\), cuánto baja \(P\) por cada radián del servo. También negativa \\
\(h\) & altura de la cabina sobre el piso, \(h=R_w-y_P\) \\
\midrule
\multicolumn{2}{l}{\textbf{Los coeficientes de velocidad} (sección 5)}\\
\midrule
\(c_Q\) & velocidad del punto \(Q\) por cada rad/s del servo, mirando desde la cabina. Es un vector, en m/rad \\
\(c_P\) & el de \(P\) (el eje de la rueda). El más grande de todos \\
\(c_{G_{AD}},\,c_{G_{BC}},\,c_{G_{CDP}}\) & los de los tres centros de masa \\
\(u\) & velocidad de la cabina por cada rad/s del servo, mirando desde el piso \\
\midrule
\multicolumn{2}{l}{\textbf{Las masas y las inercias}}\\
\midrule
\(m_{AD},\,m_{BC},\,m_{CDP}\) & masa de la manivela, del balancín y del acoplador. 23.2, 5.6 y 15.6 g \\
\(m_P\) & rueda más motor, que cuelgan de \(P\). 182 g \\
\(m_c\) & masa de la cabina, o sea todo lo que no es pata. 667 g \\
\(n\) & cantidad de patas. 2 \\
\(I_{AD},\,I_{BC},\,I_{CDP}\) & inercia de cada pieza respecto de \emph{su propio} centro de masa \\
\midrule
\multicolumn{2}{l}{\textbf{Lo que entra desde afuera}}\\
\midrule
\(\tau\) & par del servo sobre su manivela, positivo en el sentido en que crece \(\theta\) \\
\(b_A,b_B,b_C,b_D\) & fricción viscosa en cada articulación (sección 8) \\
\(g\) & gravedad \\
\bottomrule
\end{longtable}}

\section{Paso 1: los ángulos en función de \(\theta\)}

Todo el mecanismo queda definido por \(\theta\). Los ángulos se sacan con la ley del coseno, apoyándose en la
diagonal \(BD\), que parte el cuadrilátero en dos triángulos: \(ABD\) y \(BDC\). La figura de la página
siguiente los muestra todos.

Primero la diagonal, con el triángulo \(ABD\), donde el ángulo en \(A\) vale \(\theta+45^\circ\):
\begin{equation}
BD=\sqrt{AB^2+AD^2-2\,AB\,AD\cos(\theta+45^\circ)} .
\label{eq:BD}
\end{equation}
Con \(BD\) ya conocida, los dos triángulos quedan con los tres lados conocidos, así que todos sus ángulos
salen por ley del coseno:
\begin{align}
\beta_1&=\cos^{-1}\!\left(\frac{AD^2-AB^2-BD^2}{-2\,AB\,BD}\right), &
\beta_2&=\cos^{-1}\!\left(\frac{CD^2-BC^2-BD^2}{-2\,BC\,BD}\right), \label{eq:beta}\\
\alpha_1&=\cos^{-1}\!\left(\frac{AB^2-BD^2-AD^2}{-2\,BD\,AD}\right), &
\alpha_2&=\cos^{-1}\!\left(\frac{BC^2-BD^2-CD^2}{-2\,BD\,CD}\right), \label{eq:alfa}
\end{align}
y de ahí el ángulo del balancín y el giro del acoplador:
\begin{equation}
\beta=\beta_1+\beta_2,\qquad\qquad \boxed{\;\psi=180^\circ-\theta-\alpha_1-\alpha_2\;}
\label{eq:psi}
\end{equation}
La segunda sale de mirar el punto \(D\): la dirección \(D\!\to\!A\) forma \(180^\circ-\theta\) con la
horizontal, y desde ahí hay que girar \(\alpha_1\) para llegar a \(D\!\to\!B\) y \(\alpha_2\) más para llegar a
\(D\!\to\!C\).

Las derivadas \(\beta'\) y \(\psi'\) (cuánto gira cada barra por radián del servo) salen de derivar
\eqref{eq:beta} a \eqref{eq:psi}; la cuenta está hecha en \texttt{dinamica\_resumen.pdf} y el resultado es
\begin{equation}
\beta'=-\bigl(\cot\alpha_1+\cot\alpha_2\bigr)\frac{AB\,AD\sin(\theta+45^\circ)}{BD^2},\qquad
\psi'=-1+\bigl(\cot\beta_1+\cot\beta_2\bigr)\frac{AB\,AD\sin(\theta+45^\circ)}{BD^2}.
\label{eq:derivadas}
\end{equation}

\textbf{De acá en adelante no se vuelve a tocar la geometría.} Todo lo que sigue usa \(\beta\), \(\psi\),
\(\beta'\) y \(\psi'\) como números que ya están calculados para cada \(\theta\).

\begin{landscape}
\vspace*{\fill}
\begin{center}
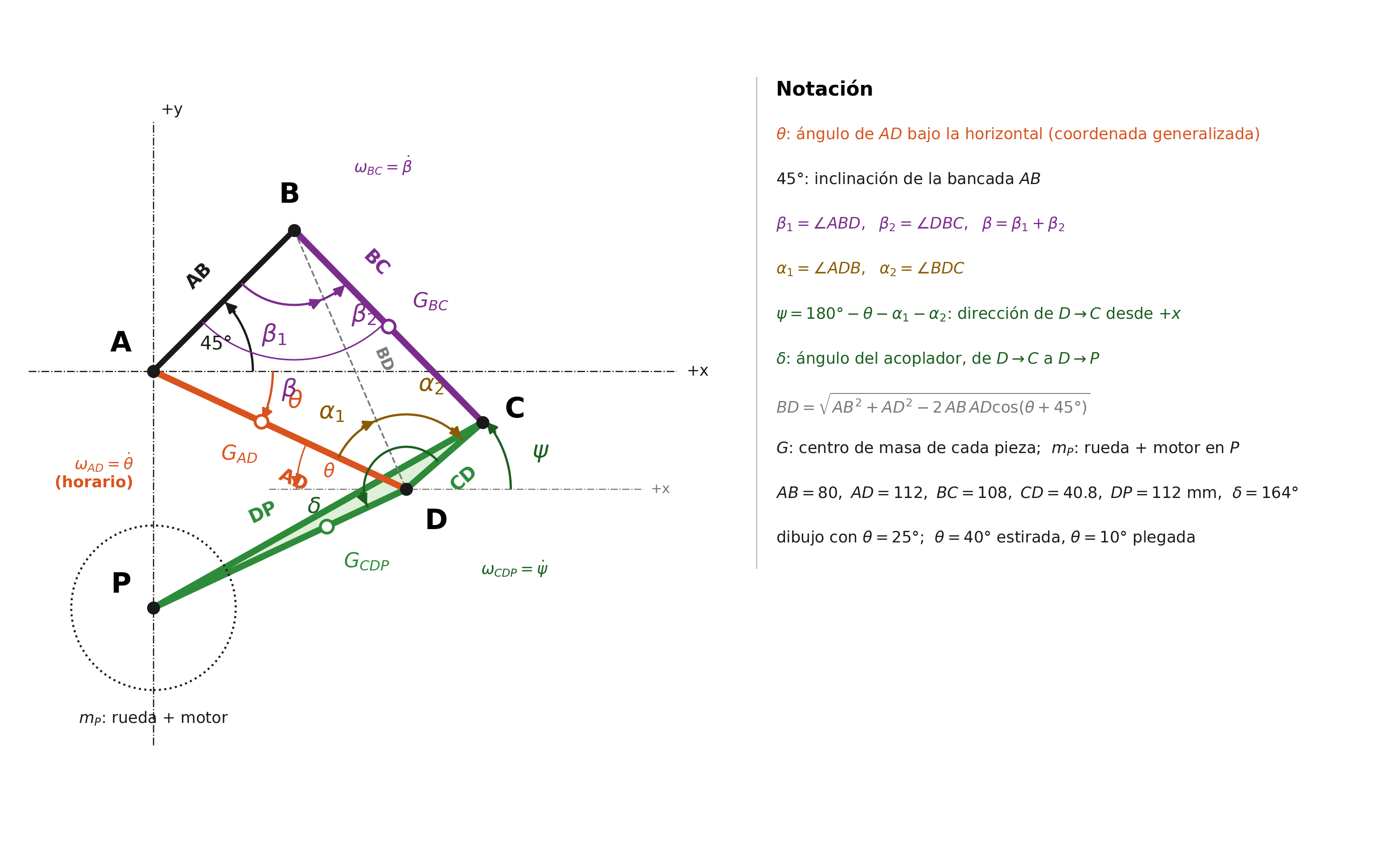
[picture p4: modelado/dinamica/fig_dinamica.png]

\end{center}
\vspace*{\fill}
\end{landscape}

\section{Paso 2: las alturas}

Con los ángulos ya resueltos, las posiciones son trigonometría directa. La que importa para todo lo que sigue
es la del eje de la rueda:
\begin{equation}
y_P(\theta)=-AD\sin\theta+DP\sin(\psi+\delta),
\label{eq:yP}
\end{equation}
que es negativa porque \(P\) está por debajo de \(A\).

Y acá viene lo propio del robot apoyado. Como la rueda toca el piso, su eje \(P\) queda siempre a la altura
\(R_w\), no importa qué haga el servo. Entonces, si \(A\) está a una altura \(Y_A\) y \(P\) está \(y_P\) por
debajo de \(A\), la condición de apoyo \(Y_A+y_P=R_w\) da
\begin{equation}
\boxed{\;h(\theta)=R_w-y_P(\theta)\;}
\label{eq:h}
\end{equation}
La altura de la cabina es una función de \(\theta\). No hay una coordenada nueva: mover el servo es subir y
bajar la cabina, y \(y_P\) (que ya venía de la cinemática) es el que dice cuánto. El panel (a) de la figura de
la página siguiente lo muestra.

\section{Paso 3: las velocidades}

\textbf{Primero, desde la cabina.} Para cada punto \(Q\) del mecanismo se define \(c_Q\), su velocidad por
cada rad/s del servo, medida parándose sobre la cabina:
\begin{equation}
\mathbf{v}^{\,\text{cabina}}_Q=c_Q(\theta)\,\dot\theta .
\label{eq:cQ}
\end{equation}
Son vectores que se calculan de una vez con los ángulos del paso 1. Con \(\mathbf{k}\times(x,y)=(-y,x)\):
\begin{align}
c_{G_{AD}}&=-\,\mathbf{k}\times G_{AD}, & &\text{la manivela gira alrededor de } A \text{ a } -\dot\theta; \label{eq:cAD}\\
c_{G_{BC}}&=\beta'\,\mathbf{k}\times(G_{BC}-B), & &\text{el balancín gira alrededor de } B \text{ a } \beta'\dot\theta; \label{eq:cBC}\\
c_Q&=c_D+\psi'\,\mathbf{k}\times(Q-D), & &\text{el acoplador, para } Q=P \text{ o } Q=G_{CDP}. \label{eq:cCDP}
\end{align}
El más grande es \(c_P\) (el del eje de la rueda): en \(\theta=25^\circ\) mide 199 mm/rad, o sea que por cada
radián que gira el servo la rueda se aleja 199 mm de la cabina. Panel (b) de la figura.

\textbf{Ahora, desde el piso.} Llamamos \(u\) a la velocidad de la cabina por cada rad/s del servo. Como la
cabina solo se traslada, la velocidad de cualquier punto \(Q\) de la pata vista desde el piso es la de la
cabina más la que tenía respecto de ella:
\begin{equation}
\mathbf{v}_Q=\bigl(u+c_Q\bigr)\dot\theta .
\label{eq:vpiso}
\end{equation}
La rueda está quieta, o sea \(\mathbf{v}_P=0\), y de ahí sale \(u\):
\begin{equation}
\boxed{\;u=-c_P\;}
\label{eq:u}
\end{equation}
Es el mismo vector cambiado de signo: lo que la rueda bajaba respecto de la cabina, ahora lo sube la cabina
respecto del piso. Con eso, todas las velocidades quedan:
\begin{center}\small
\begin{tabular}{ll}
\toprule
la cabina & \(-c_P\,\dot\theta\) \quad (sube) \\
la rueda y el motor, en \(P\) & \(0\) \quad (están quietos) \\
cada centro de masa \(G\) de la pata & \(\bigl(c_G-c_P\bigr)\dot\theta\) \\
\bottomrule
\end{tabular}
\end{center}
Panel (c) de la figura. Las velocidades angulares no cambian, porque la cabina no gira: la manivela sigue a
\(-\dot\theta\), el balancín a \(\beta'\dot\theta\) y el acoplador a \(\psi'\dot\theta\).

\begin{landscape}
\vspace*{\fill}
\begin{center}
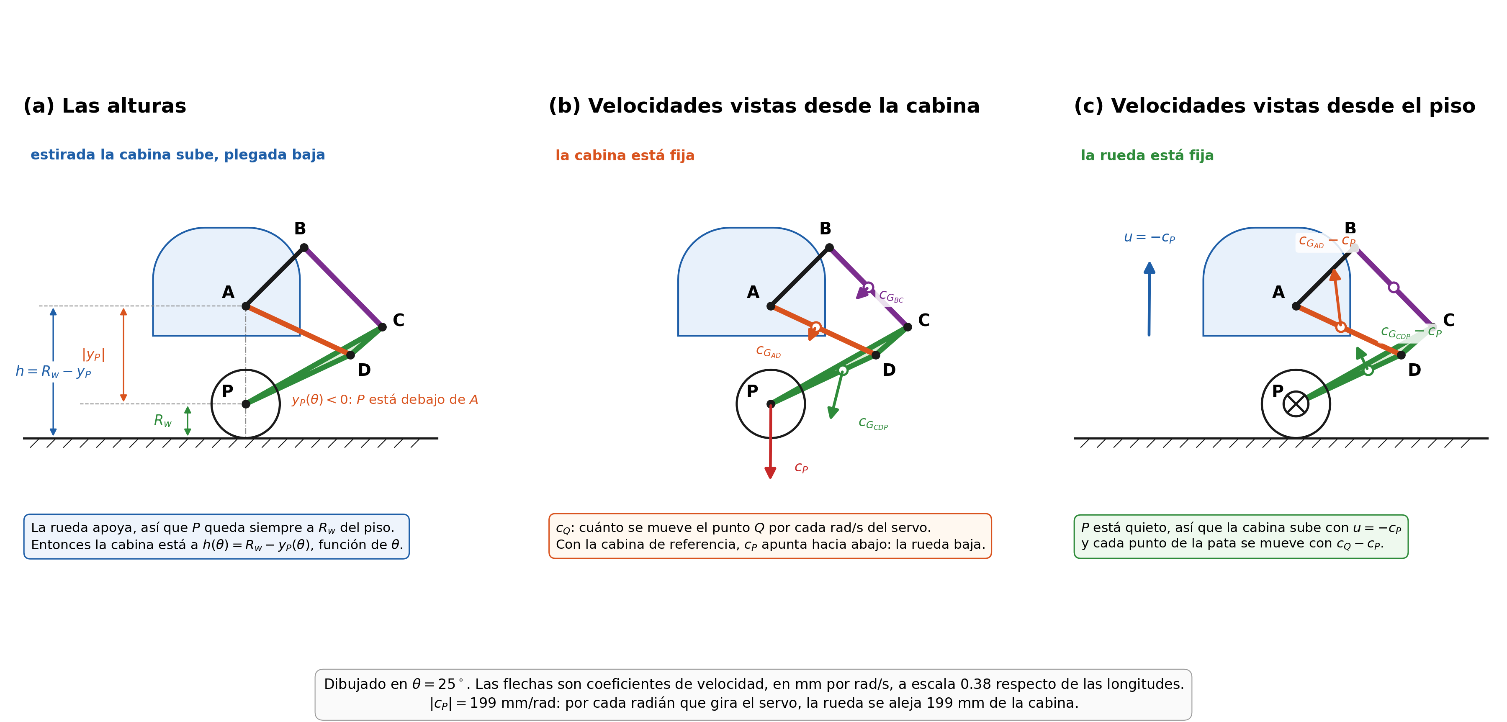
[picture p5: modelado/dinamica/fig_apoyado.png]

\end{center}
\vspace*{\fill}
\end{landscape}

\section{Paso 4: la energía cinética \(K\)}

Cada cuerpo aporta la traslación de su centro de masa más su giro propio. Poniendo las velocidades del paso 3:
\begin{equation}
\begin{aligned}
K={}&\tfrac12\,m_{AD}\bigl|c_{G_{AD}}-c_P\bigr|^2\dot\theta^2 \;+\; \tfrac12\,I_{AD}\,\dot\theta^2
  &&\text{manivela: traslada y gira}\\
+{}&\tfrac12\,m_{BC}\bigl|c_{G_{BC}}-c_P\bigr|^2\dot\theta^2 \;+\; \tfrac12\,I_{BC}\,\beta'^2\dot\theta^2
  &&\text{balancín: traslada y gira a }\beta'\dot\theta\\
+{}&\tfrac12\,m_{CDP}\bigl|c_{G_{CDP}}-c_P\bigr|^2\dot\theta^2 \;+\; \tfrac12\,I_{CDP}\,\psi'^2\dot\theta^2
  &&\text{acoplador: traslada y gira a }\psi'\dot\theta\\
+{}&\;0
  &&\text{rueda y motor: están quietos}\\
+{}&\tfrac12\,\frac{m_c}{n}\bigl|c_P\bigr|^2\dot\theta^2
  &&\text{la cabina, que sube y baja}
\end{aligned}
\label{eq:K}
\end{equation}
Todos los términos tienen \(\dot\theta^2\) de factor común, así que
\begin{equation}
K=\tfrac12\,I_{eq}(\theta)\,\dot\theta^2,
\label{eq:KIeq}
\end{equation}
\begin{equation}
\boxed{\;
\begin{aligned}
I_{eq}(\theta)={}&I_{AD}+I_{BC}\,\beta'^2+I_{CDP}\,\psi'^2\\
&+m_{AD}\bigl|c_{G_{AD}}-c_P\bigr|^2+m_{BC}\bigl|c_{G_{BC}}-c_P\bigr|^2+m_{CDP}\bigl|c_{G_{CDP}}-c_P\bigr|^2\\
&+\frac{m_c}{n}\bigl|c_P\bigr|^2
\end{aligned}
\;}
\label{eq:Ieq}
\end{equation}
\(I_{eq}\) (la inercia equivalente) es lo que el servo siente en su eje. Depende de \(\theta\) porque las
relaciones de transmisión \(\beta'\) y \(\psi'\) y el vector \(c_P\) cambian con la posición. El último
término, el de la cabina, es el 93 por ciento del total.

\section{Paso 5: la energía potencial \(U\)}

Solo gravedad, con las alturas medidas desde el piso:
\begin{equation}
U=g\left[\frac{m_c}{n}\,\underbrace{(R_w-y_P)}_{\text{cabina}}
+m_{AD}\,h_{G_{AD}}+m_{BC}\,h_{G_{BC}}+m_{CDP}\,h_{G_{CDP}}
+m_P\,\underbrace{R_w}_{\text{constante}}\right],
\label{eq:U}
\end{equation}
donde la altura de cada centro de masa de la pata es \(h_G=R_w+(y_G-y_P)\), es decir la del eje de la rueda
más lo que ese punto esté por encima de \(P\).

Dos cosas para notar. La cabina entra con \(R_w-y_P\), que es \eqref{eq:h}, y es el término que manda. Y la
rueda entra con \(R_w\), que es constante: al derivar desaparece, porque la rueda no sube ni baja.

La derivada sale directo, porque la velocidad vertical de cada punto por unidad de \(\dot\theta\) es la segunda
componente de su vector de velocidad:
\begin{equation}
\boxed{\;
U'(\theta)=g\left[\frac{m_c}{n}\bigl(-c_{P,y}\bigr)
+m_{AD}\bigl(c_{G_{AD},y}-c_{P,y}\bigr)+m_{BC}\bigl(c_{G_{BC},y}-c_{P,y}\bigr)+m_{CDP}\bigl(c_{G_{CDP},y}-c_{P,y}\bigr)\right]
\;}
\label{eq:dU}
\end{equation}
con \(c_{Q,y}\) la componente vertical de \(c_Q\). Como \(c_{P,y}\) es negativa, el primer término es positivo:
\(U\) crece con \(\theta\), o sea que estirar la pata es levantar el robot, y por eso el peso siempre tiende a
plegarla.

\section{Paso 6: lo que no sale de \(K\) ni de \(U\)}

Quedan dos cosas: el par del servo y la fricción. Las dos entran por su trabajo virtual, no por el
lagrangiano.

\textbf{El par del servo.} \(\tau\) actúa directamente sobre \(\theta\), así que su fuerza generalizada es
\(\tau\) sin ningún factor. Es la incógnita que buscamos.

\textbf{La fricción.} Hay una articulación en cada esquina del cuadrilátero, y en cada una hay roce
proporcional a la velocidad angular \emph{relativa} entre las dos piezas que une. Con las velocidades
angulares del paso 3 (la cabina quieta, la manivela a \(-\dot\theta\), el balancín a \(\beta'\dot\theta\) y el
acoplador a \(\psi'\dot\theta\)), esas velocidades relativas son:
\begin{center}\small
\begin{tabular}{llll}
\toprule
Articulación & Une & Velocidad relativa & En \(\theta=25^\circ\) \\
\midrule
\(A\) & cabina con manivela (es el eje del servo) & \(-\dot\theta\) & \(1.00\,\dot\theta\) \\
\(B\) & cabina con balancín & \(\beta'\dot\theta\) & \(0.95\,\dot\theta\) \\
\(C\) & balancín con acoplador & \((\psi'-\beta')\,\dot\theta\) & \(1.91\,\dot\theta\) \\
\(D\) & manivela con acoplador & \((\psi'+1)\,\dot\theta\) & \(1.96\,\dot\theta\) \\
\bottomrule
\end{tabular}
\end{center}
La función de disipación de Rayleigh junta las cuatro,
\(D=\tfrac12\bigl[b_A\dot\theta^2+b_B(\beta'\dot\theta)^2+b_C((\psi'-\beta')\dot\theta)^2+b_D((\psi'+1)\dot\theta)^2\bigr]\),
y el par de roce que ve el servo es \(-\partial D/\partial\dot\theta=-b_{eq}(\theta)\,\dot\theta\), con
\begin{equation}
\boxed{\;b_{eq}(\theta)=b_A+b_B\,\beta'^2+b_C\,(\psi'-\beta')^2+b_D\,(\psi'+1)^2\;}
\label{eq:beq}
\end{equation}
Tiene la misma forma que \(I_{eq}\): cada articulación entra con el cuadrado de su relación de transmisión.
Las que más rozan son \(C\) y \(D\), que giran casi el doble que el servo.

\textbf{Atención: hoy los cuatro valen cero.} No están medidos, así que el modelo no tiene ninguna pérdida y
por eso es optimista en las simulaciones rápidas. \(b_A\) es el más importante de los cuatro, porque incluye
la reductora del propio servo. Para medir \(b_{eq}\): dejar el servo libre, soltar la pata desde estirada y
cronometrar cuánto tarda en plegarse; se ajusta \(b_A\) hasta que la simulación tarde lo mismo. Si al medir
aparece un par de arranque que no depende de la velocidad, es fricción seca y se agrega como
\(-\operatorname{sign}(\dot\theta)\bigl[c_A+c_B|\beta'|+c_C|\psi'-\beta'|+c_D|\psi'+1|\bigr]\).

\textbf{Lo que no aparece.} La reacción del piso \(N\) no está en ninguna parte. El punto de contacto no se
mueve, así que no hace trabajo, y el peso que soporta ya está contado dentro de \(U\).

\section{Paso 7: la ecuación}

Con \(L=K-U\), y usando que \(K=\tfrac12 I_{eq}(\theta)\dot\theta^2\) depende de \(\theta\) además de
\(\dot\theta\):
\begin{equation}
\frac{\partial L}{\partial\dot\theta}=I_{eq}\,\dot\theta,\qquad
\frac{\dd}{\dd t}\frac{\partial L}{\partial\dot\theta}=I_{eq}\,\ddot\theta+I_{eq}'\,\dot\theta^2,\qquad
\frac{\partial L}{\partial\theta}=\tfrac12\,I_{eq}'\,\dot\theta^2-U',
\label{eq:parciales}
\end{equation}
donde \(I_{eq}'=\dd I_{eq}/\dd\theta\). Restando y poniendo las fuerzas del paso 6 del lado derecho:
\begin{equation}
\boxed{\;
I_{eq}(\theta)\,\ddot\theta\;+\;\tfrac12\,I_{eq}'(\theta)\,\dot\theta^2\;+\;U'(\theta)
\;=\;\tau\;-\;b_{eq}(\theta)\,\dot\theta
\;}
\label{eq:final}
\end{equation}
Leída de izquierda a derecha: para mover la pata el servo tiene que vencer la inercia, un término extra que
aparece porque esa inercia cambia con la posición, el peso, y el roce.

Los dos casos que más se usan salen de acá. Con la pata quieta (\(\dot\theta=\ddot\theta=0\)), el par para
sostenerla es
\begin{equation}
\tau_{est}(\theta)=U'(\theta).
\label{eq:tauest}
\end{equation}
Y para simular, despejando la aceleración, con el estado \(x=(\theta,\dot\theta)\):
\begin{equation}
\ddot\theta=\frac{\tau-b_{eq}\,\dot\theta-\tfrac12 I_{eq}'\,\dot\theta^2-U'}{I_{eq}} .
\label{eq:estado}
\end{equation}

\section{Resumen: qué términos aparecieron}

\begin{center}\small
\begin{tabular}{l p{10.6cm}}
\toprule
\textbf{En \(K\)} & \\
\midrule
Entró la cabina & \(\tfrac12(m_c/n)|c_P|^2\dot\theta^2\). Es el término más grande, el 93 por ciento de
  \(I_{eq}\). No estás subiendo la rueda, estás subiendo la cabina \\
Salió la rueda & el término de \(m_P\) desaparece: con la rueda apoyada, \(P\) no se traslada \\
Cambió la referencia & las velocidades pasan de \(c_Q\) a \(c_Q-c_P\): todo se mide respecto de \(P\) \\
Salió el giro de la rueda & \(\tfrac12 I_P\omega^2\) no depende de \(\theta\), lo impone el motor de tracción \\
\midrule
\textbf{En \(U\)} & \\
\midrule
Entró la cabina & \((m_c/n)\,g\,(R_w-y_P)\), otra vez el término que manda \\
Salió la rueda & su altura es \(R_w\), constante, y al derivar se va \\
\midrule
\textbf{Fuera de \(K\) y \(U\)} & \\
\midrule
El par del servo & \(\tau\), que entra directo sobre \(\theta\) \\
La fricción & \(-b_{eq}(\theta)\,\dot\theta\), con las cuatro articulaciones pesadas por el cuadrado de su
  relación de transmisión. Hoy vale cero por falta de medición \\
No aparece \(N\) & el contacto no se mueve, no hace trabajo \\
\midrule
\textbf{En la ecuación} & \\
\midrule
\(\tfrac12 I_{eq}'\dot\theta^2\) & aparece porque \(I_{eq}\) cambia con \(\theta\). Es el equivalente al
  término centrífugo de un mecanismo de inercia variable \\
\bottomrule
\end{tabular}
\end{center}

\section{Números}

Con los valores de la tabla de la sección 2, y \(n=2\):

\begin{center}\small
\begin{tabular}{lrrr}
\toprule
 & \(\theta=10^\circ\) (plegada) & \(\theta=25^\circ\) & \(\theta=40^\circ\) (estirada) \\
\midrule
Altura de la cabina \(h\) [mm] & 70.2 & 127.9 & 177.2 \\
\(\beta'\), \(\psi'\) [rad/rad] & \(-0.703\), \(1.260\) & \(-0.950\), \(0.964\) & \(-1.161\), \(1.120\) \\
\(|c_P|=|y_P'|\) [mm/rad] & 250 & 199 & 182 \\
\(I_{eq}\) [g\,m\(^2\)] & 22.24 & 14.13 & 11.92 \\
\(\tau_{est}=U'\) [kg\,cm] & 9.06 & 7.20 & 6.58 \\
\midrule
Factor de \(b_C\) en \(b_{eq}\) & 3.85 & 3.66 & 5.20 \\
Factor de \(b_D\) en \(b_{eq}\) & 5.11 & 3.86 & 4.49 \\
\bottomrule
\end{tabular}
\end{center}

La postura más exigente es la plegada: ahí el brazo \(|c_P|\) es máximo y el servo tiene que dar 9.1 kg\,cm
solo para sostener el robot quieto, contra los 40 kg\,cm del servo elegido. La inercia también es máxima ahí, casi
el doble que estirada.

\section{Qué no incluye este modelo}

Supone que la cabina no gira, es decir que el control de equilibrio la mantiene derecha mientras la pata se
mueve, y que las dos patas van juntas. No dice nada sobre el equilibrio en sí ni sobre el avance: para eso
hace falta el modelo de tres grados de libertad \((x,\varphi,\theta)\), que es el paso siguiente y que
reutiliza todo lo de las secciones 3 a 5.

Tampoco vale mientras el robot está en el aire, porque ahí la rueda no está quieta y \(u\) es otro. Ese caso,
y el de la pata en un banco con la cabina amurada, están en \texttt{dinamica\_resumen.pdf} junto con el
cálculo de la caída de un escalón.

Las masas y las inercias son estimaciones (la primera iteración del CAD escalada a 80, y las fichas del motor y del servo), y las cuatro fricciones son cero. Los dos pendientes de
medición son pesar las piezas impresas y hacer el ensayo de caída libre de la pata.

\section{Archivos}

\begin{itemize}
\item \texttt{dinamica\_pata.m}: sección 1 los parámetros, para editar; sección 2 los tres casos; sección 3 una
  simulación de agacharse y pararse; sección 4 la verificación contra los diagramas de cuerpo libre; sección 5
  la caída de un escalón; sección 6 la fuerza radial en el eje del servo. El caso de este documento se elige con la cadena \texttt{'parado'}.
\item \texttt{fig\_dinamica.py} \(\to\) \texttt{fig\_dinamica.png}: los ángulos de la sección 3.
\item \texttt{fig\_apoyado.py} \(\to\) \texttt{fig\_apoyado.png}: las alturas y los coeficientes de velocidad.
\item \texttt{../cinematica/parametros\_geometria.m}: la geometría, misma fuente para todo el proyecto.
\end{itemize}

\end{document}

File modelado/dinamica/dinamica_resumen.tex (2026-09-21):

\documentclass[11pt,a4paper]{article}
\usepackage[utf8]{inputenc}
\usepackage[T1]{fontenc}
\usepackage[spanish,es-noshorthands]{babel}
\usepackage[margin=2.1cm]{geometry}
\usepackage{amsmath,amssymb}
\usepackage{graphicx}
\usepackage{booktabs}
\usepackage{xcolor}
\usepackage{pdflscape}
\usepackage[colorlinks=true,linkcolor=blue!50!black,urlcolor=blue!50!black]{hyperref}
\setlength{\parskip}{4pt}
\setlength{\parindent}{0pt}
\newcommand{\dd}{\mathrm{d}}
\title{Dinámica de la pata del Segway por Lagrange\\
\large Coordenada generalizada \(\theta\). Tres casos: banco, robot parado y robot en el aire}
\author{Proyecto Segway con patas -- Robótica II, UNCUYO}
\date{\today}

\begin{document}
\maketitle

Cada pata es una cuatro barras \(ABCD\) con la bancada \(AB\) rígida con la cabina. El servo en \(A\) gira la
manivela \(AD\); el acoplador \(C\)--\(D\)--\(P\) lleva el eje de la rueda \(P\), que sube y baja casi en
vertical. El mecanismo tiene un solo grado de libertad, \(\theta\).

Lo que cambia de una situación a otra no es el mecanismo sino \emph{qué está quieto}. En un banco de pruebas,
con la cabina amurada, el servo mueve la rueda. Con el robot parado, la rueda apoya en el piso y el servo
mueve la cabina, que pesa casi cuatro veces más. En el aire no hay nada quieto. Son tres dinámicas distintas con
la misma geometría, y se obtienen todas de una sola ecuación cambiando un único vector.

\section{Notación y parámetros}

El dibujo del mecanismo (\texttt{fig\_dinamica.png}) está en la página siguiente. Ejes: origen en \(A\), \(x\)
hacia la derecha del dibujo (hacia atrás del robot), \(y\) hacia arriba. Los ángulos absolutos se miden desde
\(+x\) en sentido antihorario.
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

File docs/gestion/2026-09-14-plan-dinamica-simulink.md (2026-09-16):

# Plan de integración de la dinámica de la pata en Simulink

Fecha de revisión: 2026-09-14  
Backlog operativo: [`BACKLOG.md`](../../BACKLOG.md)  
Alcance: continuar el trabajo del commit `c5602f1` sin perder la planta y las pruebas ya existentes.

Estado de ejecución al 2026-09-14: entorno MCP actualizado; fases 2 y 3 completadas para el banco
reducido; equivalencia numérica, energía y sensibilidad al solver de la fase 4 aprobadas (12/12 pruebas).
Continúan pendientes la transición híbrida contacto-vuelo, los parámetros del CAD nuevo y `planta_v3`.
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

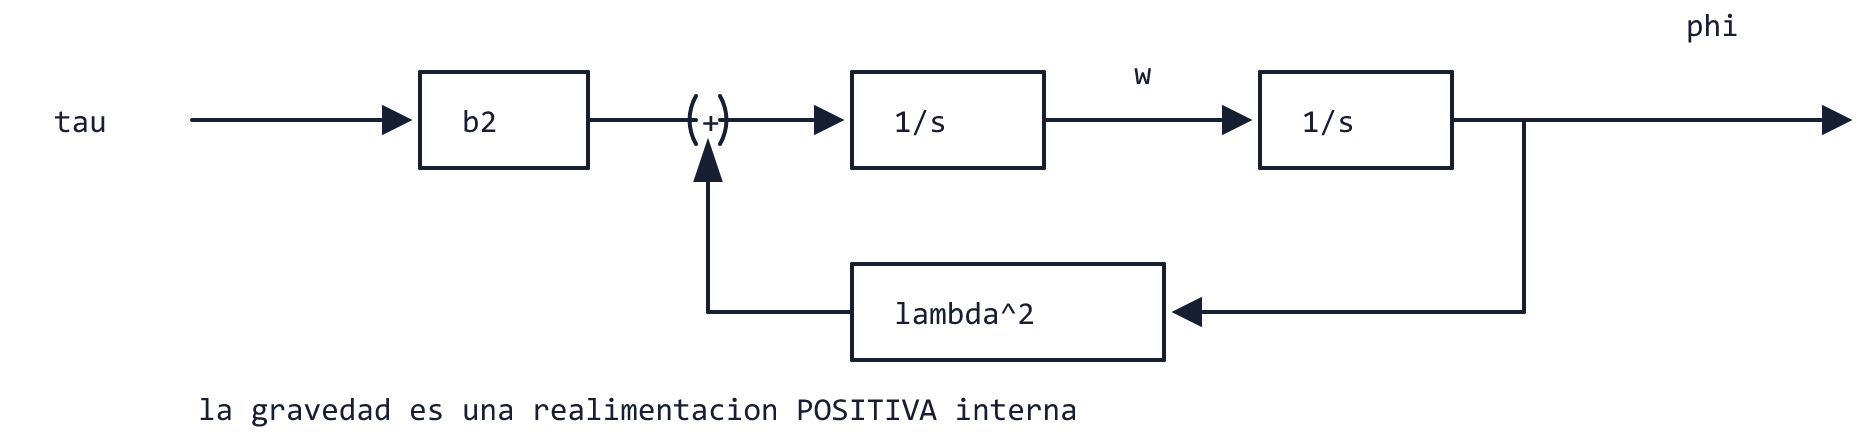
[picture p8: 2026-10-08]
modelado/planta/pendulo_invertido/diagramas/lazo_gravedad.png

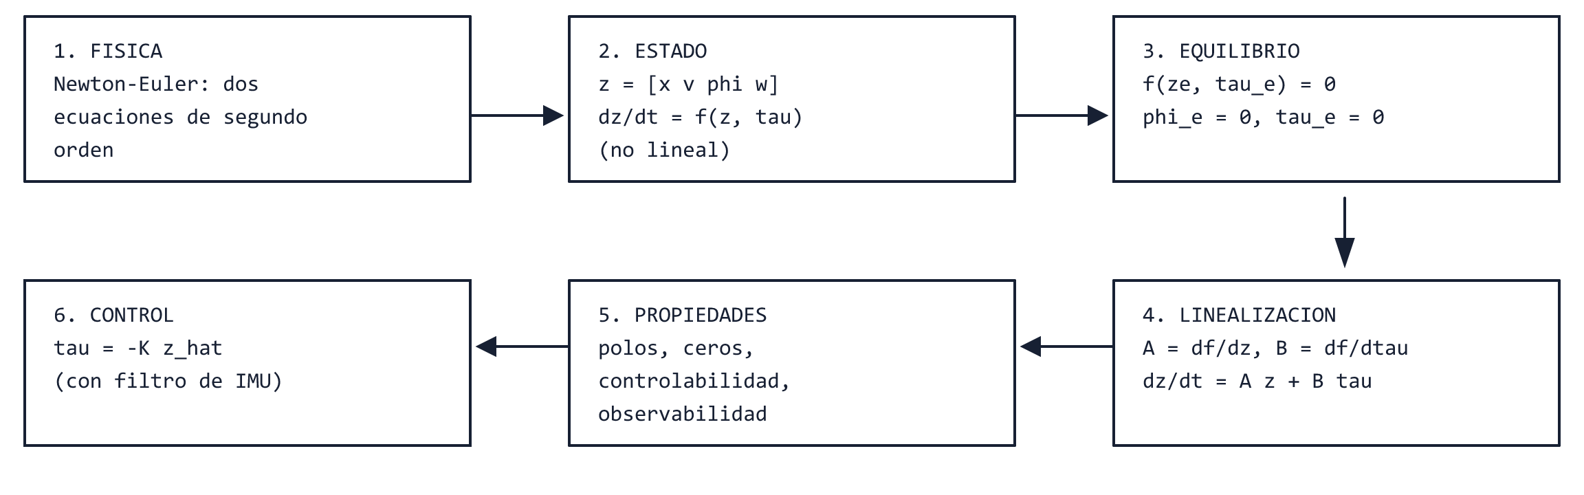
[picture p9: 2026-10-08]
modelado/planta/pendulo_invertido/diagramas/ruta_modelado_estado.png

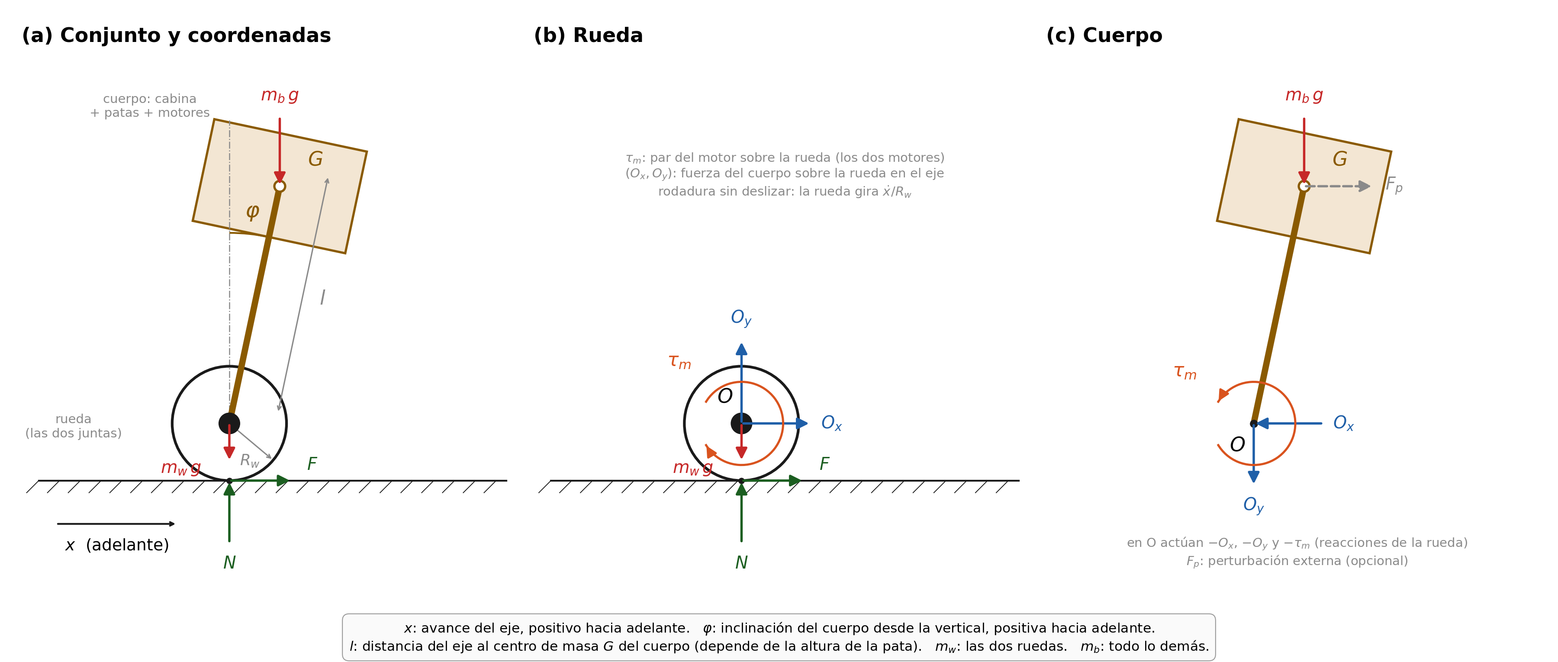
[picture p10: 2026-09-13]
modelado/dcl/dcl_segway.png

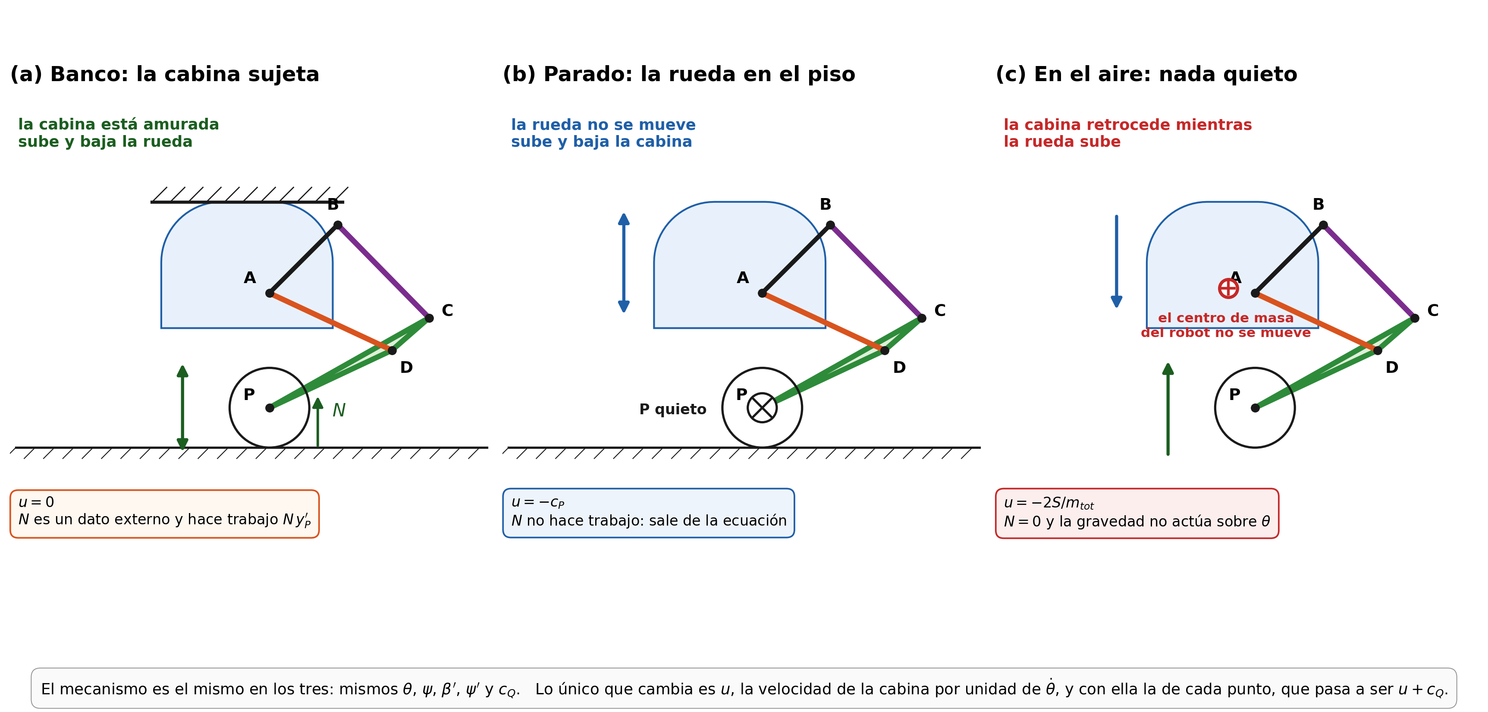
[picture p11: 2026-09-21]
modelado/dinamica/fig_casos.png

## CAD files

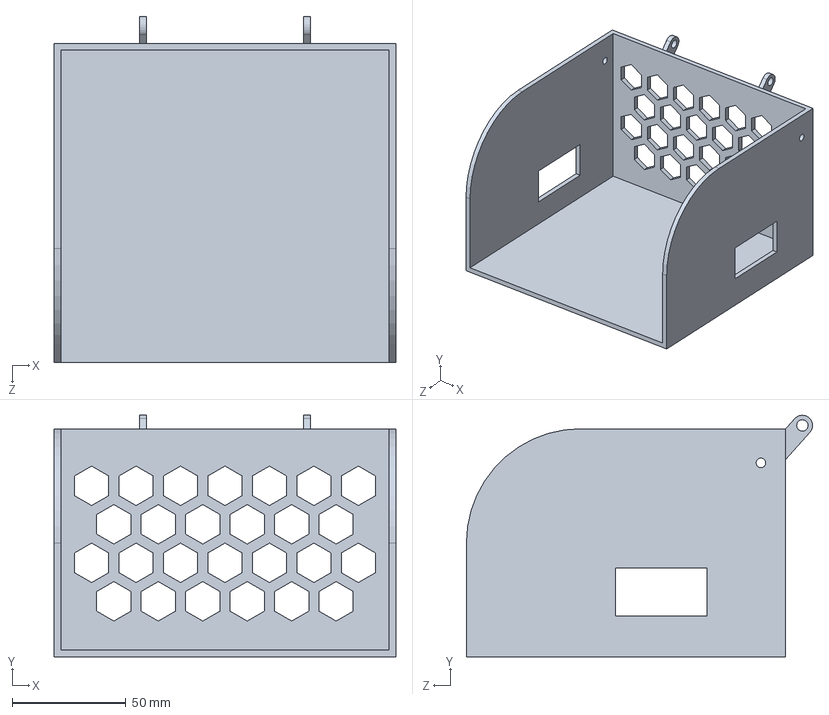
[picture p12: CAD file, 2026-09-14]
diseño_mecanico/segunda_iteracion/completo/asml_cabeza_v31v4.SLDPRT
150.0 x 106.0 x 151.8 mm

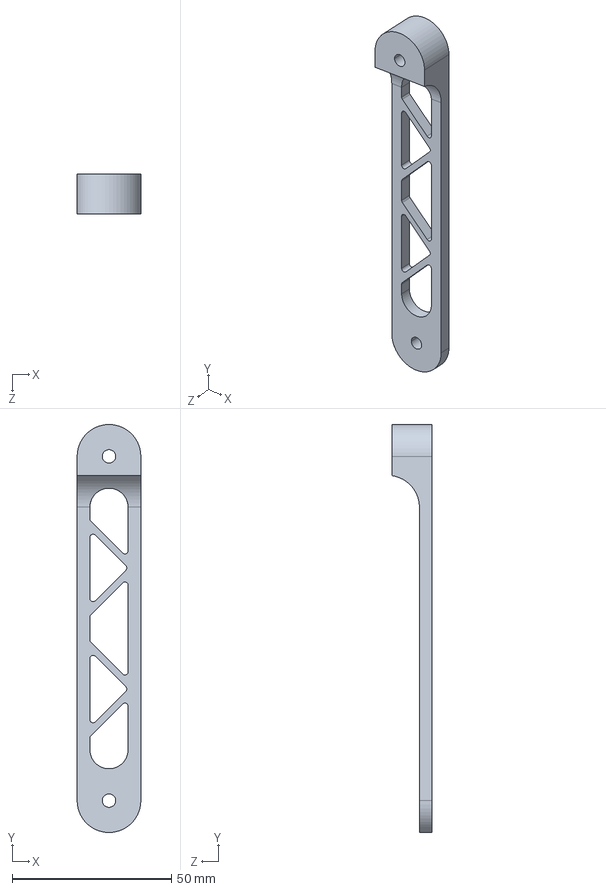
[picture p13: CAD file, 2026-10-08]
diseño_mecanico/step_printing/asml_eslabon_BC_externav4.STEP
20.0 x 128.0 x 12.7 mm

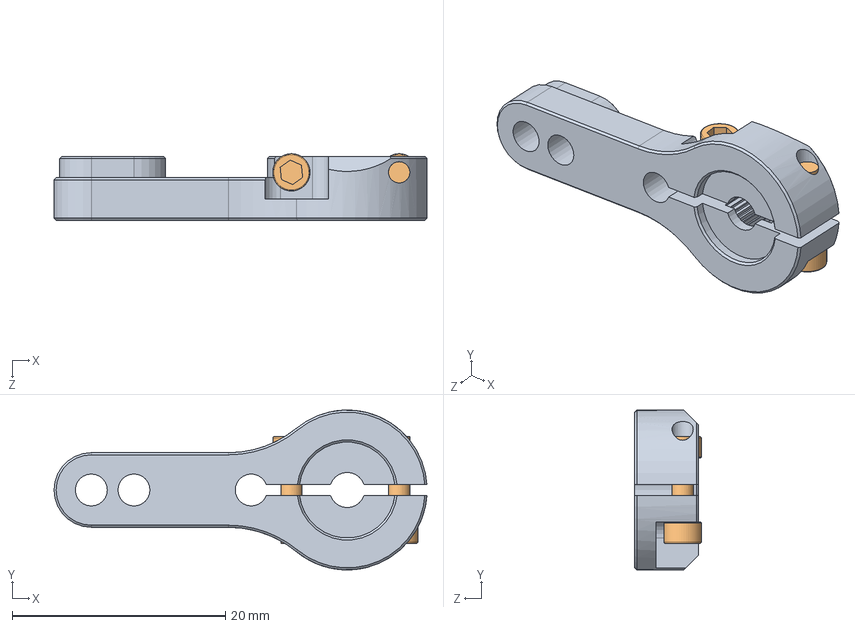
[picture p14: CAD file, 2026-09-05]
diseño_mecanico/utilidades/ds3225-mg-metal-horn-1.snapshot.4/DS3225_MG_metal_horn/Assembly_DS3225MG_Metal_Horn.SLDASM
35.0 x 15.0 x 6.25 mm
DS3225_MG_metal_horn
screw_M2x8mm x 2

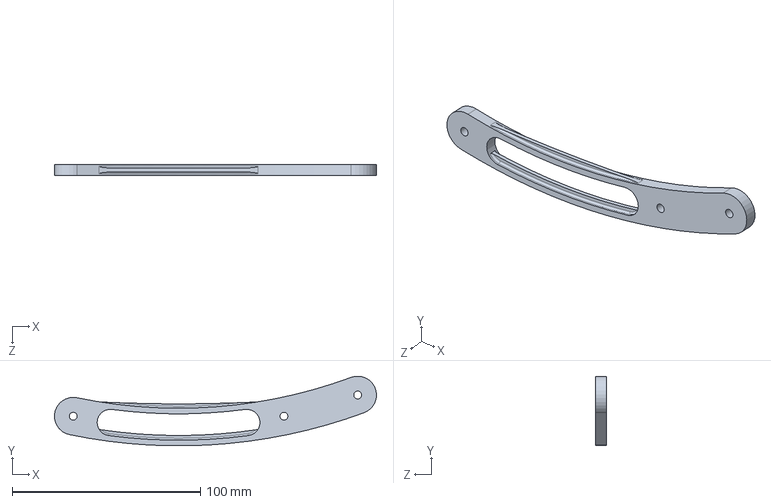
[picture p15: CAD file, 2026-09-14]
diseño_mecanico/segunda_iteracion/completo/asml_eslabon_CDP_v2v4.SLDPRT
171.2 x 36.9 x 6.00 mm

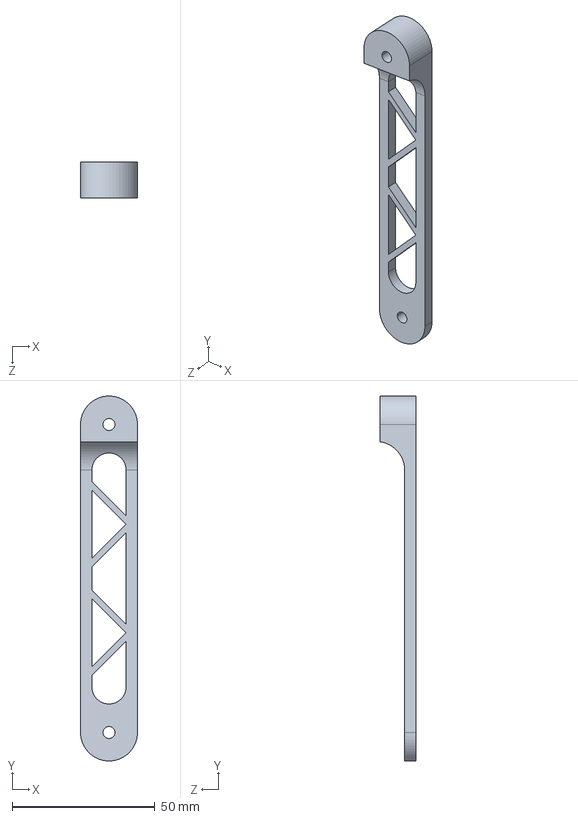
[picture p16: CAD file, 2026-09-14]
diseño_mecanico/segunda_iteracion/completo/step/asml_eslabon_BC_externav4.STEP
20.0 x 128.0 x 12.7 mm

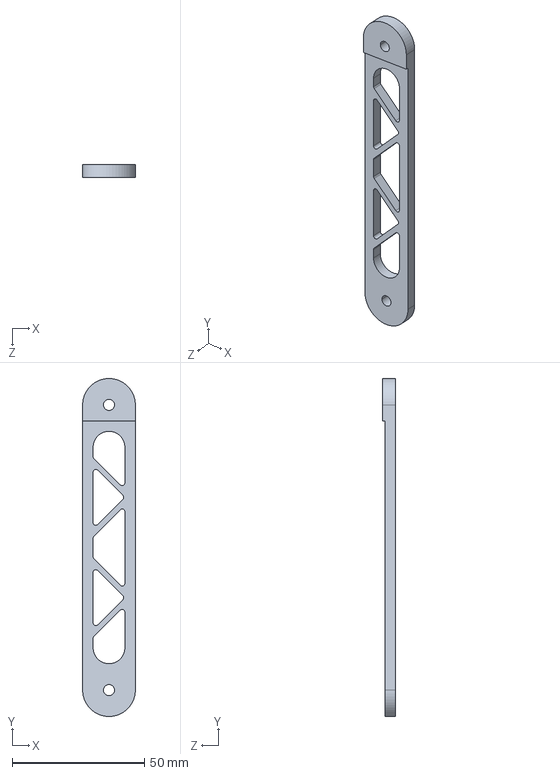
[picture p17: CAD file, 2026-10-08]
diseño_mecanico/step_printing/asml_eslabon_BCv4.STEP
20.0 x 128.0 x 5.00 mm

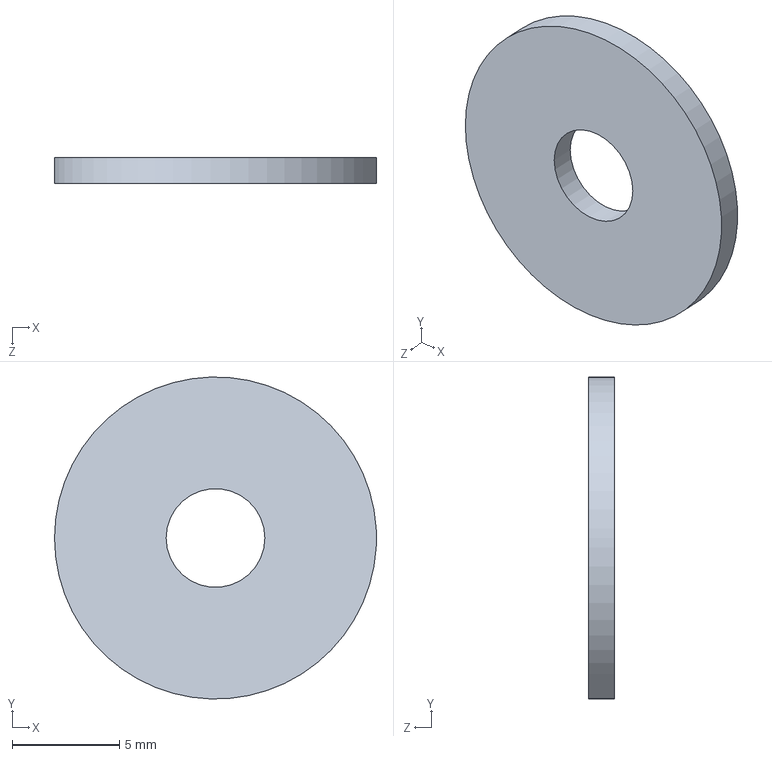
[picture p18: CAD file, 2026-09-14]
diseño_mecanico/segunda_iteracion/completo/asml_arandela_m4v4.SLDPRT
15.0 x 15.0 x 1.20 mm

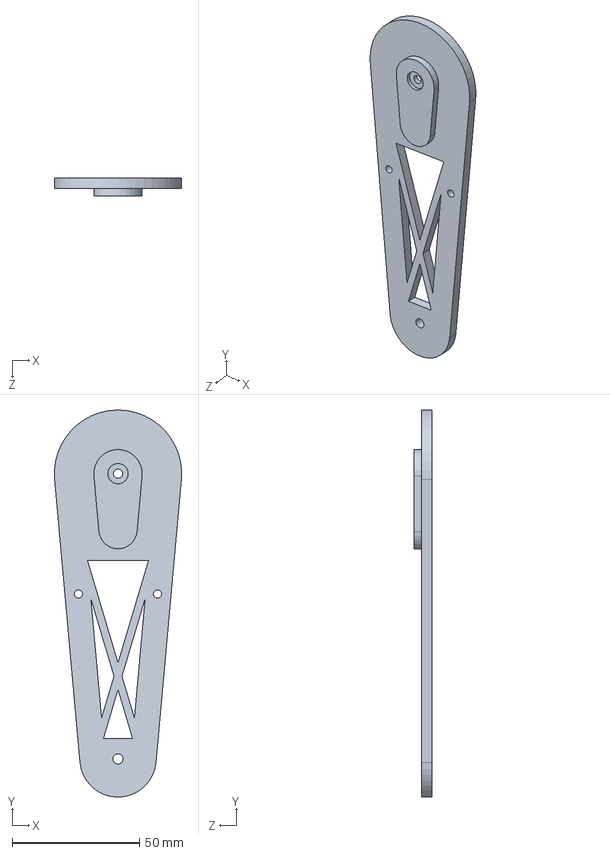
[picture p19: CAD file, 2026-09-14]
diseño_mecanico/segunda_iteracion/completo/asml_eslabon_AD_v2v4.SLDPRT
49.9 x 151.9 x 7.00 mm

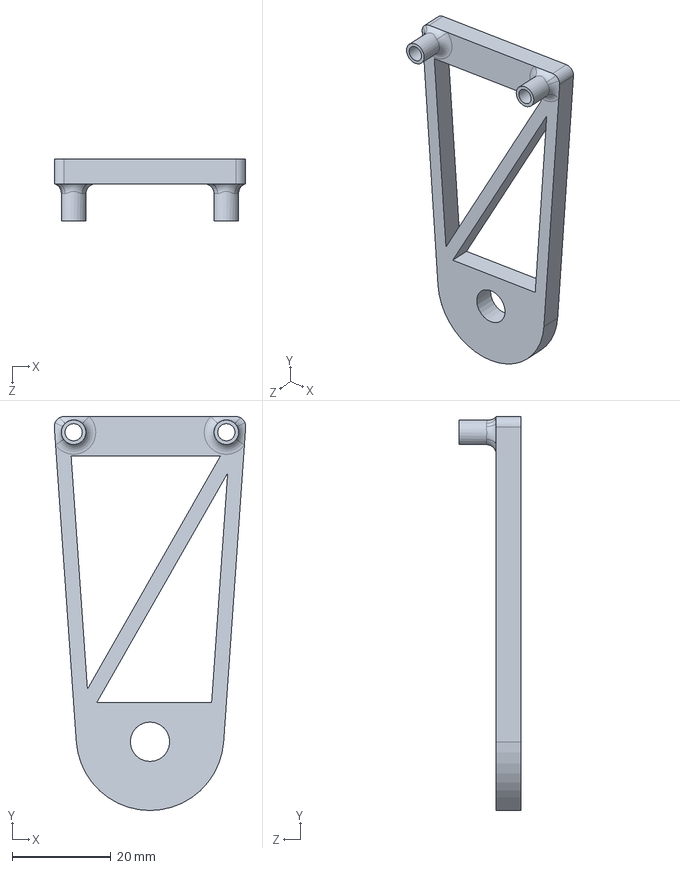
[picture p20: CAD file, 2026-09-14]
diseño_mecanico/segunda_iteracion/completo/asml_eslabon_AD_tapav4.SLDPRT
38.9 x 80.0 x 12.5 mm

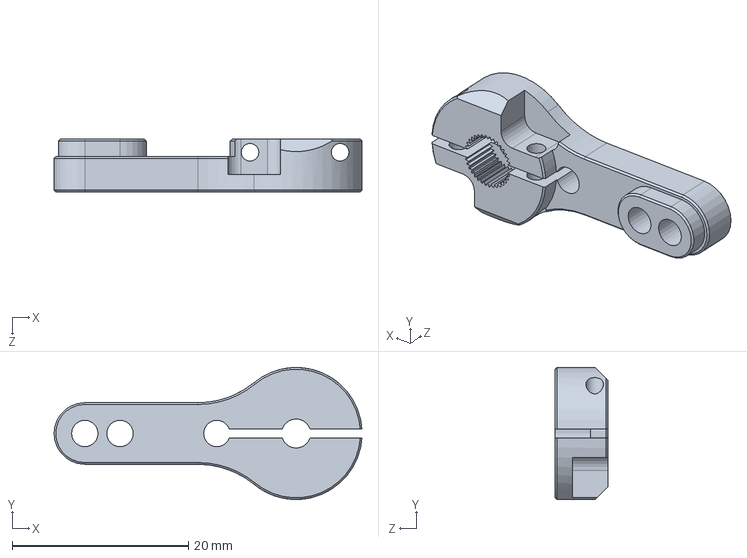
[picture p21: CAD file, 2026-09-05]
diseño_mecanico/segunda_iteracion/completo/asml_DS3225_MG_metal_hornv4.SLDPRT
35.0 x 15.0 x 6.00 mm

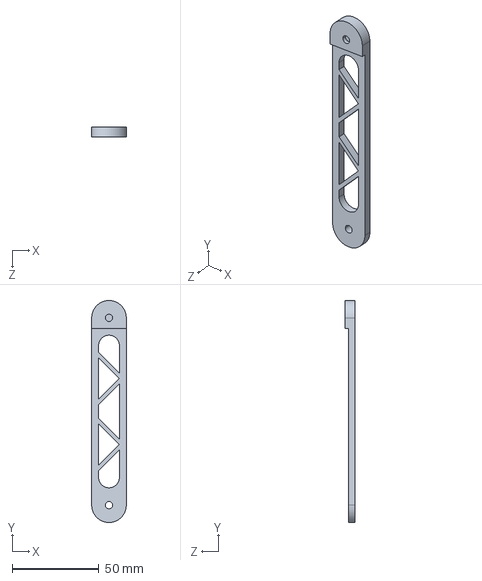
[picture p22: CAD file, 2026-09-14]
diseño_mecanico/segunda_iteracion/completo/step/asml_eslabon_BCv4.STEP
20.0 x 128.0 x 6.00 mm

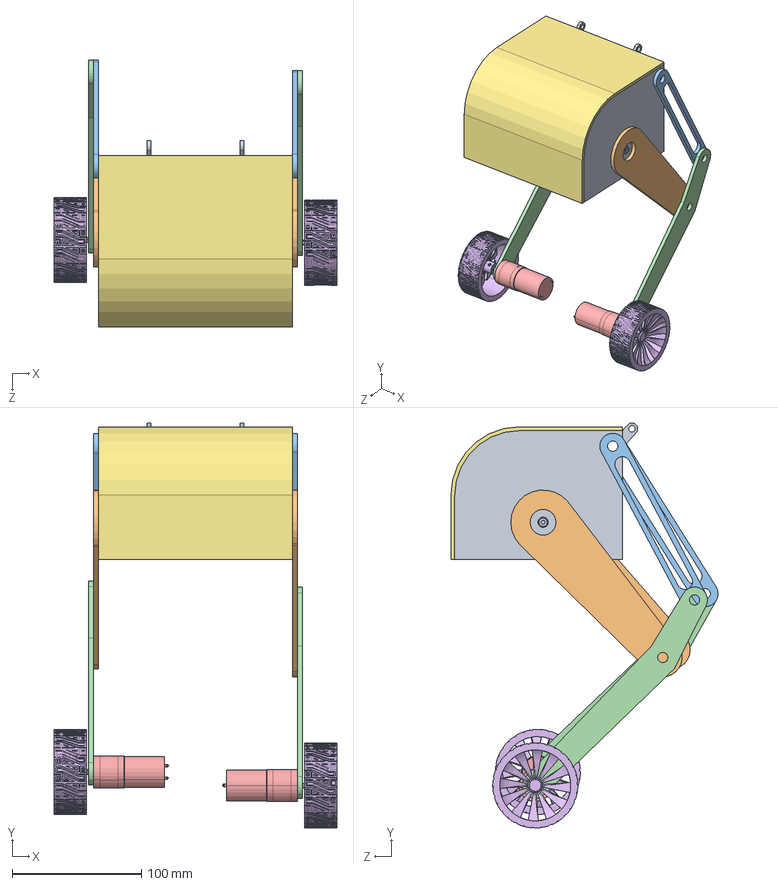
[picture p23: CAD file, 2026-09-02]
diseño_mecanico/primera_iteracion/completo.STEP
219.0 x 314.0 x 207.2 mm
cabeza_v31
eslabon_AD x 2
eslabon_BC x 2
eslabon_CDP x 2
JGA25-370 DC 12V60RPM x 2
wheel x 2
tapa_cabeza
DS3225MG 25KG x 2

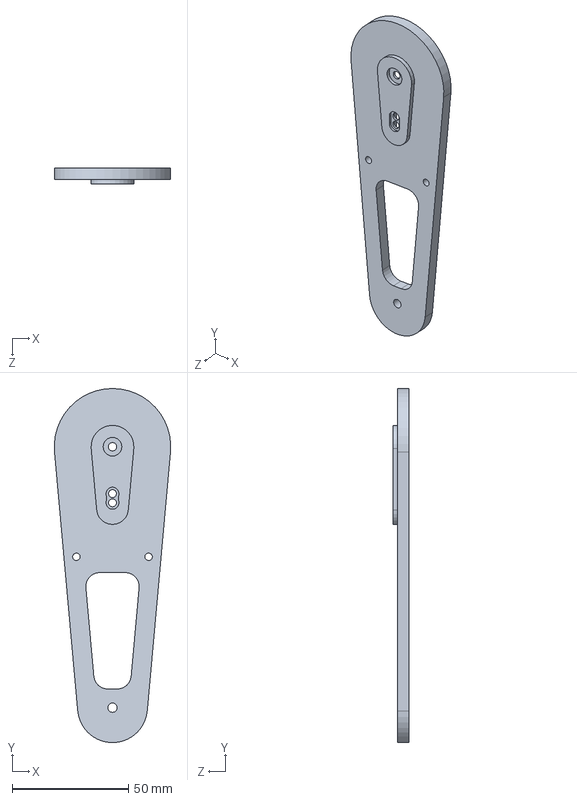
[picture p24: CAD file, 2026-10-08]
diseño_mecanico/segunda_iteracion/eslabon_AD_v2.SLDPRT
49.9 x 151.9 x 7.00 mm

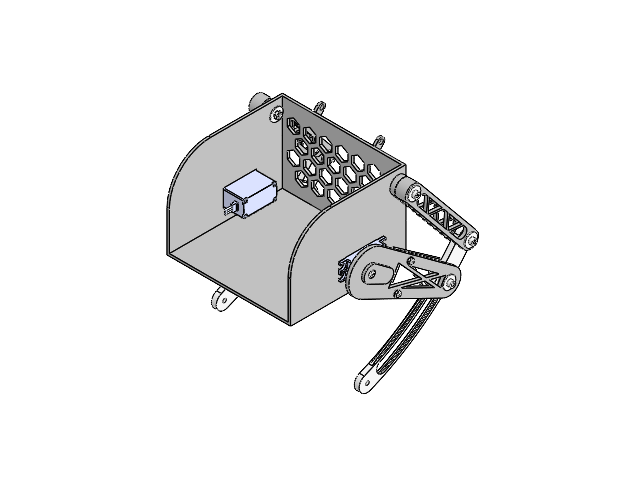
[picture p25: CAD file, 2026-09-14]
diseño_mecanico/segunda_iteracion/completo/asml_completo_v3v4.SLDASM
cabeza_v31
DS3225MG 25KG x 2
eslabon_AD_v2 x 2
DS3225_MG_metal_horn x 2
pan_head_screw_M3_l10mm_thread x 2
washer_M3 x 6
eslabon_CDP_v2 x 2
arandela_m4 x 22
eslabon_BC_externa x 2
eslabon_BC x 2
eslabon_AD_tapa x 2
socket_head_cap_screw_M4_l25mm_plain x 4
hexagon_nut_M4_thread x 2
socket_head_cap_screw_M3_l20mm_plain x 4
hexagon_nut_M3_plain x 4
socket_head_cap_screw_M4_l30mm_plain x 2
hexagon_nut_M4_plain x 4

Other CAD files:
diseño_mecanico/segunda_iteracion/completo/asml_DS3225MG 25KGv4.SLDPRT
diseño_mecanico/segunda_iteracion/completo/step/asml_completo_v2v4.STEP
diseño_mecanico/segunda_iteracion/completo_v3.SLDASM
diseño_mecanico/segunda_iteracion/completo/step/eslabon_CDP_v2.STEP
diseño_mecanico/segunda_iteracion/DS3225MG 25KG.SLDPRT
diseño_mecanico/segunda_iteracion/cabeza_v31.SLDPRT
diseño_mecanico/segunda_iteracion/completo/asml_completo_v2v4.SLDASM
diseño_mecanico/segunda_iteracion/completo/asml_eslabon_BC_externav4.SLDPRT
diseño_mecanico/segunda_iteracion/completo/asml_eslabon_BCv4.SLDPRT
diseño_mecanico/segunda_iteracion/completo/asml_hexagon_nut_M3_plainv4.SLDPRT
diseño_mecanico/segunda_iteracion/completo/asml_hexagon_nut_M4_plainv4.SLDPRT
diseño_mecanico/segunda_iteracion/completo/asml_hexagon_nut_M4_threadv4.SLDPRT
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

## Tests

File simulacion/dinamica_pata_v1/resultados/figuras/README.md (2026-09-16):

# Figuras exportadas del banco de dinámica

Esta carpeta se actualiza automáticamente al ejecutar
[`INICIAR_DINAMICA_PATA.m`](../../INICIAR_DINAMICA_PATA.m).

Archivos recomendados para compartir con el equipo:

- `resumen_equipo.png`: comparación completa de escenarios;
- `ultimo_run.png`: dashboard de la última simulación;
- `energia_solver.png`: validación energética y sensibilidad numérica.

Estas son las únicas tres salidas visuales del banco y se sobrescriben al ejecutar la acción correspondiente.
No se generan copias por escenario ni formatos auxiliares. Los datos y métricas detallados siguen disponibles
en las estructuras MATLAB retornadas por el lanzador.

Los gráficos son evidencia del banco reducido de una pata. No sustituyen la validación de la planta
completa del robot ni del CAD definitivo.

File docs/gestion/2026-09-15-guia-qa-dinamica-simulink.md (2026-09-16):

# Guía de QA — dinámica reducida de la pata en Simulink

Fecha: 2026-09-15  
Modelo: `simulacion/dinamica_pata_v1/dinamica_pata_simulink.slx`  
Alcance: banco reducido de un grado de libertad, casos `banco`, `parado` y `aire`.

## 1. Qué se considera terminado

El banco reproduce la ecuación dinámica reducida mediante bloques Simulink nativos. No contiene bloques
`MATLAB Function`. Las expresiones que dependen de la geometría se calculan offline y entran al modelo
como tablas 2-D indexadas por ángulo y caso.

Esto valida la dinámica de una pata bajo las restricciones declaradas. No es todavía la planta completa
del Segway: no incluye el cabeceo de la cabina, avance, ruedas, contacto completo ni transición automática
de apoyo a vuelo con recontacto.

## 2. Preparación de MATLAB

Abrir MATLAB R2023b y ejecutar:

```matlab
repo = 'D:/Usuario/Matias/Proyectos/robotica2_segway';
cd(repo)
addpath('simulacion/dinamica_pata_v1')
```

No abrir ni usar los PDF como fuente. Las ecuaciones editables están en `modelado/dinamica/*.m` y en los
documentos Markdown/TEX del repositorio.

## 3. QA rápido automatizado

Ejecutar el QA consolidado:

```matlab
r = INICIAR_DINAMICA_PATA('qa');
```

Copiar el comando sin los indicadores `>>` del Command Window. Los guiones bajos se escriben como `_`,
sin barra previa.

Resultado esperado: 12 pruebas aprobadas y ninguna fallida. La suite comprueba:

- fuente común de parámetros;
- cierre del cuatro barras y equivalencia cinemática;
- reducciones `banco`, `parado` y `aire`;
- dependencia correcta de `n_patas`;
- ecuación de estado y topes;
- supervisor de contacto en MATLAB;
- precisión de las tablas;
- derivada de la energía potencial;
- construcción reproducible y compilación del `.slx`;
- ausencia de bloques `MATLAB Function`;
- equivalencia ODE–Simulink;
- estática, señales, energía y sensibilidad al solver.

La prueba de construcción trabaja sobre una copia temporal y no reemplaza el `.slx` versionado.

## 4. Regenerar y abrir el modelo

Para abrir el `.slx`, cargar `parado_nominal` y dejar el botón **Run** listo:

```matlab
INICIAR_DINAMICA_PATA
```

Solo cuando se quiera regenerar íntegramente el modelo:

```matlab
INICIAR_DINAMICA_PATA('reconstruir')
```

La reconstrucción reemplaza `dinamica_pata_simulink.slx`. No ejecutarla si hay cambios manuales sin
guardar; toda mejora estructural permanente debe incorporarse también al constructor de `interno/`.

Para verificar que sigue compuesto solo por bloques nativos:

```matlab
mf = find_system('dinamica_pata_simulink', 'LookUnderMasks', 'all', ...
    'MaskType', 'MATLAB Function');
assert(isempty(mf), 'El modelo contiene bloques MATLAB Function');
```

## 5. Recorrido visual recomendado

### Nivel raíz

Identificar, de izquierda a derecha:

1. `theta ref`: consigna angular;
2. `tau perturbacion`: par externo adicional;
3. `normal`: carga normal externa cuando corresponde;
4. `caso`: selector `1=banco`, `2=parado`, `3=aire`;
5. `Servo PD`: controlador y límite par–velocidad;
6. `Dinamica theta`: planta no lineal de un grado de libertad;
7. bloques `log_*`: señales devueltas en el `SimulationOutput`.

### Subsistema `Servo PD`

Abrirlo y seguir este orden:

1. `error`, `Kp` y `menos Kd`: ley PD;
2. `velocidad absoluta` y `fraccion velocidad`: velocidad normalizada del servo;
3. `margen velocidad`, `margen positivo` y `limite motriz`: curva par–velocidad;
4. `potencia mecanica` y `acompanha giro`: distingue si el par acompaña el movimiento;
5. `saturacion par`: aplica límites dinámicos positivo y negativo;
6. `mas perturbacion`: agrega el par externo.

### Subsistema `Dinamica theta`

Los bloques `Ieq`, `dIeq`, `dV`, `wP`, `cCoM` y `dcCoM` son tablas. Sus dos entradas son `theta` y
`caso`. La cadena central implementa:

```text
ddtheta = (tau + tau_tope - b*dtheta + N*wP
           - 0.5*dIeq*dtheta^2 - dV) / Ieq
```

Seguir visualmente:

1. `integrador velocidad` produce `dtheta`;
2. `integrador theta` produce `theta`;
3. `dtheta cuadrado` y `termino inercial` forman `dIeq*dtheta^2`;
4. `suma pares` reúne actuación, topes, amortiguamiento, normal, inercia y gravedad;
5. `dividir por Ieq` produce `ddtheta` y cierra los dos integradores;
6. `Topes` agrega resorte-amortiguador fuera de 10°–40°;
7. la rama inferior calcula aceleración del CoM, normal estimada y `contacto valido`.

## 6. Ejecutar un escenario nominal

Con el modelo abierto, ejecutar desde la consola:

```matlab
R = INICIAR_DINAMICA_PATA('simular', 'parado_nominal');
```

La función usa `Simulink.SimulationInput`: pasa parámetros y señales sin modificar permanentemente el
modelo. También corre el ODE de referencia con las mismas entradas.

Inspeccionar las métricas:

```matlab
R.metricas
R.error
```

El comando abre y guarda automáticamente un dashboard compacto. La ruta queda disponible en:

```matlab
R.figuras.png
```

El dashboard conserva solamente seguimiento angular, esfuerzo del servo, contacto y cinco indicadores
numéricos. Velocidad, aceleración, retrato de fase y series de error permanecen en `R`, pero no se grafican
automáticamente. `ultimo_run.png` siempre apunta al último escenario ejecutado.

Referencia actual para `parado_nominal`:

- par pico aproximado: `15,383 kg cm`;
- normal mínima aproximada: `1,399 N` por rueda;
- no se detecta pérdida de contacto;
- la maniobra entra aproximadamente `0,7°` en el tope inferior.

## 7. Comparar Simulink contra el ODE

Para un caso suave, sin impacto con los topes:

```matlab
R = INICIAR_DINAMICA_PATA('simular', 'parado_validacion');
fprintf('error theta   = %.3e rad\n', R.error.theta_max)
fprintf('error dtheta  = %.3e rad/s\n', R.error.dtheta_max)

figure
subplot(2,1,1)
plot(R.t, R.theta, R.t, R.ode.theta, '--'); grid on
legend('Simulink','ODE'); ylabel('theta [rad]')
subplot(2,1,2)
plot(R.t, R.theta-R.ode.theta); grid on
ylabel('error [rad]'); xlabel('t [s]')
```

Criterios de aceptación:

- `R.error.theta_max < 1e-5 rad`;
- `R.error.dtheta_max < 1e-4 rad/s`.

Repetir con:

```matlab
INICIAR_DINAMICA_PATA('simular', 'banco_validacion');
INICIAR_DINAMICA_PATA('simular', 'aire_validacion');
```

## 8. Ejecutar todos los escenarios

```matlab
B = INICIAR_DINAMICA_PATA('barrido');
disp(B.resumen)
disp(B.archivo)
```

Esto ejecuta estática, tres maniobras nominales y tres casos suaves de validación. El resultado se guarda
en `simulacion/dinamica_pata_v1/resultados/`. También genera:

```matlab
B.figuras.resumen.png   % comparativo listo para compartir
```

El comparativo muestra únicamente uso del servo, carrera angular y margen de contacto. La tabla `B.resumen`
conserva los errores Simulink–ODE y el resto de las métricas para un análisis puntual.

## 9. QA de energía y solver

```matlab
A = INICIAR_DINAMICA_PATA('energia');
A.metricas
A.figuras.png
```

La lámina resultante conserva dos verificaciones: deriva de energía y balance disipativo. La sensibilidad al
solver se resume numéricamente en el título y permanece completa en `A.metricas`.

Valores de referencia:

- deriva relativa de energía conservativa: `7,79e-10`;
- residuo relativo disipativo: `3,76e-8`;
- diferencias finales contra el solver de referencia: orden `1e-13`.

El ensayo es suave y no activa topes. Todavía debe hacerse un estudio específico de localización de
eventos para impacto, despegue y recontacto.

## 10. Figuras después del botón Run

Al abrir mediante `INICIAR_DINAMICA_PATA`, el botón **Run** queda configurado para exportar el dashboard al
terminar. No hace falta copiar señales ni ejecutar otro script. Los archivos de consulta rápida son:

- `resultados/figuras/ultimo_run.png`: última simulación individual;
- `resultados/figuras/resumen_equipo.png`: último comparativo;
- `resultados/figuras/energia_solver.png`: último análisis energético.

Para regenerar la figura del Run más reciente sin volver a simular:

```matlab
G = INICIAR_DINAMICA_PATA('graficos');
```

## 11. Cómo interpretar resultados anómalos

| Síntoma | Revisar primero |
|---|---|
| El modelo pide variables inexistentes | Ejecutar primero `INICIAR_DINAMICA_PATA`; luego el botón Run queda inicializado |
| El ángulo supera 10°–40° | Señal `tau_tope`, ganancias `k_tope/c_tope` y tamaño de paso |
| Diferencia ODE–Simulink grande solo al tocar el tope | Localización temporal del evento; usar primero un escenario `*_validacion` |
| Par recortado | `tau_max`, `w_nl` y bloques de la curva par–velocidad en `Servo PD` |
| `normal_estimada` es `NaN` | Es esperado en `banco` y `aire`; solo aplica a `parado` |
| `contacto_valido` cae a cero | La normal estimada dejó de ser positiva; la transición automática a vuelo sigue pendiente |
| El estático de 25° queda por debajo de 25° | El PD no tiene todavía prealimentación de gravedad (`CTL-101`) |

## 12. Checklist de aceptación manual

- [ ] Las 12 pruebas pasan.
- [ ] El modelo se regenera y abre sin errores.
- [ ] La búsqueda de `MATLAB Function` devuelve vacío.
- [ ] Se identifican claramente `Servo PD`, `Dinamica theta` y `Topes`.
- [ ] Los seis bloques de tabla usan `theta` y `caso`.
- [ ] Los tres casos suaves cumplen los umbrales ODE–Simulink.
- [ ] El par permanece dentro de la curva configurada del servo.
- [ ] La normal solo se interpreta en `parado`.
- [ ] Se documenta si una corrida activa los topes.
- [ ] No se presenta este banco como validación de la planta completa del robot.
- [ ] `ultimo_run.png`, `resumen_equipo.png` y `energia_solver.png` abren y contienen ejes/leyendas legibles.

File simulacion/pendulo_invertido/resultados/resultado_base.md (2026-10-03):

# Resultado del pendulo invertido

- Corrida: 2026-10-03 14:58:43 -0300 (Buenos Aires).
- MATLAB: 25.2.0.2998904 (R2025b).
- Commit base: `2d2d49371fb23f0e366d05ca71a5e1090f9d3137`; incorpora archivos locales del modelo nuevo.
- Variante: `segunda_iteracion`; postura fija: 25.0 grados.
- Fuente: `modelado/parametros/parametros_fisicos.m`. Masas/CoM/inercias estimados; rotor y electricidad omitidos.
- Solver: ode45; RelTol 1.0e-09; AbsTol 1.0e-11; MaxStep 1.0e-03 s.

| Parametro | Valor SI |
|---|---:|
| Masa cuerpo [kg] | 1.059800000 |
| Masa ruedas [kg] | 0.060000000 |
| Radio [m] | 0.033000000 |
| Distancia P-G [m] | 0.074773119 |
| J_G [kg m2] | 0.00439283676 |
| J_ruedas [kg m2] | 3.267e-05 |
| Chasis en equilibrio [grados] | -0.154442 |
| b_eje [N m s/rad] | 0.0002 |
| b_phi [N m s/rad] | 0.001 |
| b_x [N s/m] | 0 |
| mu | 0.7 |

Estado inicial `[x, v, phi, omega]`: `[0 0 0.0087266463 0]` (SI). Par total: 0.000000 N m.

Duracion solicitada 1.000000 s; limite angular 20.0 grados.

Fin en **0.355549 s**: Limite angular de demostracion.

- Error angular hasta 5 grados: 0.0114605446 grados.
- Normal minima: 8.655035343 N; margen minimo de adherencia: 5.920424538 N.
- Residuo maximo del balance de energia: 4.09221268e-15 J.
- Rango de controlabilidad: 4 de 4.

Orden de estado: `[x; v; phi; omega]`. Entrada: par total de las ruedas.

```text
A =
[0 1 0 0;0 -0.425355536 11.0318789 -0.0282276695;0 0 0 1;0 -3.85413333 160.067211 -0.333090009]
B =
[0;-70.1836635;0;-635.931999]
Autovalores =
[0;-12.9571769;-0.159664985;12.3583963]
```

El equilibrio superior es inestable. El lineal aproxima la dinamica local;
esta corrida no identifica parametros ni valida un controlador fisico.

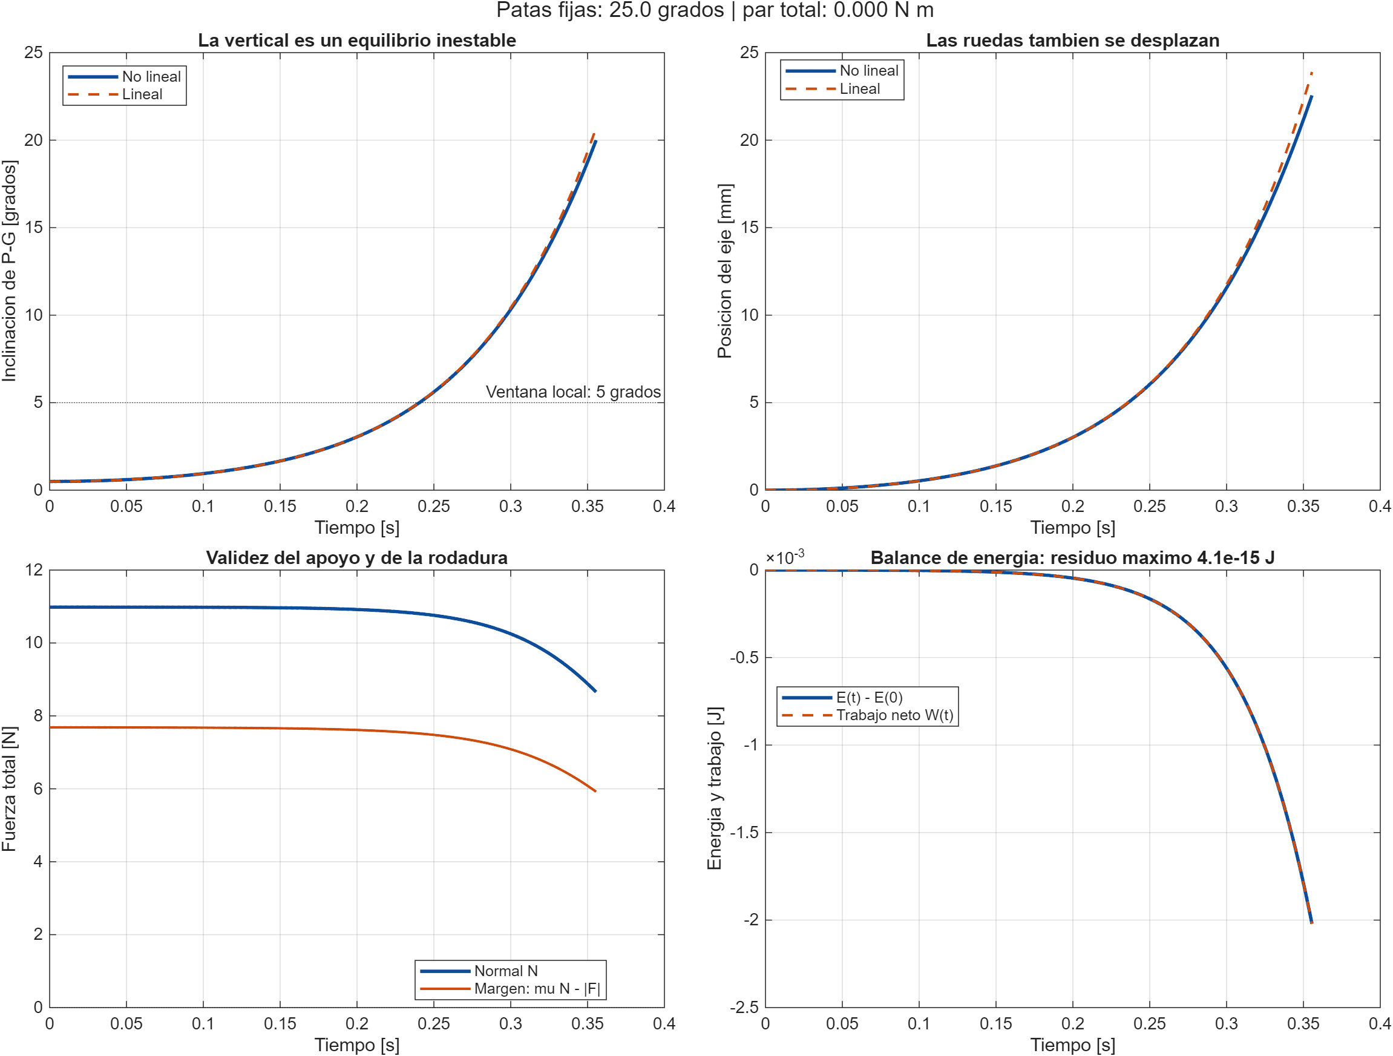
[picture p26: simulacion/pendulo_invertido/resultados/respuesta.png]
Respuesta


[Datos](trayectoria.csv) | [MATLAB](resultado_base.mat)

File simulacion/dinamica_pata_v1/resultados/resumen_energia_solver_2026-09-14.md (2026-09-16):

# Balance de energía y sensibilidad al solver

Fecha: 2026-09-14  
Modelo: `dinamica_pata_simulink.slx`  
Función reproducible: `interno/analizar_energia_solver.m`, expuesta por `INICIAR_DINAMICA_PATA('energia')`
Datos completos: `energia_solver_2026-09-14.mat` (`A`, formato MAT v7)  
Caso: `aire`, sin control, sin carga externa y sin topes; `theta(0)=25°`, `theta_dot(0)=0,4 rad/s`.

## Configuraciones comparadas

| Nombre | Solver | Paso máximo [s] | RelTol | AbsTol |
|---|---|---:|---:|---:|
| referencia | `ode45` | 1e-4 | 1e-10 | 1e-12 |
| nominal | `ode45` | 1e-3 | 1e-9 | 1e-11 |
| contraste | `ode23` | 5e-4 | 1e-8 | 1e-10 |

Las configuraciones se aplican con `Simulink.SimulationInput`; el archivo `.slx` conserva su
configuración nominal.

## Resultados

| Métrica | Resultado |
|---|---:|
| deriva relativa máxima de energía, referencia conservativa | 7,7876e-10 |
| residuo relativo del balance con `b=0,02 N m s/rad` | 3,7561e-8 |
| diferencia final `ode45` nominal vs referencia, norma infinito | 3,9851e-13 |
| diferencia final `ode23` vs referencia, norma infinito | 5,0832e-13 |
| rango angular observado | 25,000° a 34,513° |

La energía usada es, por servo,
`E = 0,5 Ieq(theta) theta_dot^2 + V(theta)`. Para el ensayo disipativo se verificó
`E(t)-E(0)+integral(b theta_dot^2 dt) = 0`. La trayectoria no alcanzó los topes, por lo que el resultado
caracteriza la ecuación suave y no mezcla energía de impacto.

Conclusión: el solver nominal `ode45`, paso máximo 1 ms y tolerancias `1e-9/1e-11` es suficiente para
este ensayo suave. Esta evidencia no sustituye el estudio pendiente de localización de eventos en topes,
despegue y recontacto (`TST-103`).

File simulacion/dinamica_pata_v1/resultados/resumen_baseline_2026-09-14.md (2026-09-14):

# Primer barrido del banco dinámico

Fecha: 2026-09-14  
Commit base: `195348960cc9bb739252c19acbf99ed4d09bb4ed`  
Estado del modelo: cambios de esta corrida todavía no confirmados en Git  
MATLAB: R2023b Update 6  
Modelo: `dinamica_pata_simulink.slx`  
Parámetros: variante nominal `corregido`, servo DS3225MG a 6,8 V, límite 2,4 N·m  
Solver: `ode45`, paso máximo 0,001 s, `RelTol=1e-9`, `AbsTol=1e-11`  
Datos completos: `corridas_baseline_2026-09-14.mat`

## Resultados

| Escenario | θ mín. [°] | θ máx. [°] | Par pico [kg·cm] | Normal mín. [N] | Error θ [rad] | Error θ̇ [rad/s] |
|---|---:|---:|---:|---:|---:|---:|
| estático 25° | 23,639 | 25,000 | 12,106 | 1,358 | 1,17e-10 | 2,60e-9 |
| banco nominal | 9,312 | 40,000 | 13,269 | N/A | 2,05e-4 | 4,50e-3 |
| parado nominal | 9,305 | 40,000 | 15,383 | 1,399 | 2,68e-4 | 7,07e-3 |
| aire nominal | 9,995 | 40,000 | 0,673 | N/A | 1,72e-8 | 1,44e-6 |
| banco validación | 20,792 | 26,866 | 11,249 | N/A | 1,55e-9 | 4,61e-8 |
| parado validación | 20,782 | 26,875 | 12,630 | 1,358 | 2,34e-9 | 6,14e-8 |
| aire validación | 22,003 | 27,996 | 0,331 | N/A | 4,76e-10 | 5,07e-8 |

## Lectura técnica

- Las señales suaves de validación cumplen holgadamente los umbrales MATLAB–Simulink de `1e-5 rad` y
  `1e-4 rad/s` en los tres casos.
- Las maniobras nominales apoyadas penetran aproximadamente 0,7° el tope inferior. En esa discontinuidad,
  diferencias de localización de evento entre los dos solvers elevan el error transitorio; no es un error
  de las tablas dentro de la carrera.
- En `parado_nominal` la normal mínima es positiva (`1,399 N` por rueda), por lo que esta maniobra no
  requiere transición a vuelo.
- El par máximo nominal es `15,383 kg·cm`, por debajo del límite configurado de `24,465 kg·cm`.
- El punto estático de 25° se asienta en 23,639° porque el PD no incluye todavía prealimentación de
  gravedad. Es comportamiento esperado y una mejora clara para el siguiente controlador.

Las normales de `banco` y `aire` se informan como N/A: en banco la carga es una entrada externa y en aire
no hay contacto. La salida booleana `contacto_valido` solo se activa en el caso `parado` con normal positiva.

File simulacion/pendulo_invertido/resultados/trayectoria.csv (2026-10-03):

t_s | x_m | v_ms | phi_deg | omega_rads | phi_lineal_deg | normal_N | tangencial_N | energia_J | residuo_J
0 | 0 | 0 | 0.5 | 0 | 0.5 | 10.9842721307953 | -0.00288774521739783 | 0.77735944895222 | 0
0.000355549261943688 | 6.08366017957197e-09 | 3.42195589721157e-05 | 0.50000505788753 | 0.000496548959026971 | 0.500005058384839 | 10.9842722972809 | -0.0028962113126792 | 0.777359448952135 | -7.4939358550112e-17
0.000711098523887377 | 2.4332356169478e-08 | 6.84296534318583e-05 | 0.500020230217154 | 0.000993002285536026 | 0.500020232206135 | 10.9842723856004 | -0.00290473367294619 | 0.77735944895154 | 5.88364398159144e-17
0.00106664778583106 | 5.47428462806567e-08 | 0.000102630977513863 | 0.500045515143218 | 0.00148937004378437 | 0.500045519617939 | 10.9842723957942 | -0.0029133124586526 | 0.777359448949927 | -3.39602511041396e-17
0.00142219704777475 | 9.73121355829774e-08 | 0.000136824225025864 | 0.500080911025063 | 0.00198566229413074 | 0.500080918979412 | 10.9842723278965 | -0.00292194783135301 | 0.777359448946785 | -8.67314663139743e-17
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

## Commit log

2026-08-29 add: 2 mejoras al script de simulacion de mecanismo
    - Ahora es posible introducir valores numericos directamente sin usar barra deslizante
    - Es posible variar los valores y ver el movimiento al mismo tiempo
    [ensamble_case.SLDASM, ensamble_motores.SLDASM, eslabon_pantorrilla_flexible.3mf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]
2026-09-01 4 bar mech
    [completo.SLDASM, link_0.SLDPRT, link_1.SLDPRT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]
2026-09-02 primera iteración
    [DS3225MG 25KG.SLDPRT, DS3225MG 25KG.STEP, JGA25-370 DC 12V60RPM.SLDPRT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]
2026-09-03 cinematica directa
    [01-myfirst.urdf, 02-multipleshapes.urdf, 03-origins.urdf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]
2026-09-05 un avance mas
    [Assembly_DS3225MG_Metal_Horn.SLDASM, DS3225MG 25KG.SLDPRT, DS3225_MG_metal_horn.SLDPRT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]
2026-09-08 pata en c
    [cabeza_v31.SLDPRT, completo.SLDASM, eslabon_CDP.SLDPRT]
2026-09-13 DCL en carpeta modelado
    diagramas de cuerpo libre, y orden en la carpeta de modelado
2026-09-14 Ultimo cad, creo que esta bueno, falta justifiacion matematica
    [DS3225MG 25KG.SLDPRT, DS3225_MG_metal_horn.SLDPRT, Parça 214 - M4x20.step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]
2026-09-14 step files
    [DS3225MG 25KG.STEP, DS3225_MG_metal_horn_Défaut.STEP, arandela_m4.STEP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]
2026-09-21 orden y ajustes de archivos
    se borro simulacion vieja ya no sirve, se arreglaron y corrigieron README, base de conocimiento, disseño mecanico, se actualizaron todos, se limpio codigo basura y desactualizado que quedo viejo.
    [01-myfirst.urdf, 02-multipleshapes.urdf, 03-origins.urdf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]
2026-09-24 correcion de consulta jueves 17
    [analisis_eslabones.xlsx, analisis_eslabones_ecuaciones.xlsx, asml_completo_v2v4.SLDASM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]
2026-10-03 pendulo invertido (NO REVISADO)
    [trayectoria.csv]
2026-10-03 modificaciones a torsion y archivos step
    [eslabon_AD_tapa.SLDPRT, eslabon_AD_v2.SLDPRT, eslabon_CDP_v2.SLDPRT]
2026-10-03 M25, V1 listo.
    Runtime corroborado
    [asml_completo_v2v4.SLDASM, asml_eslabon_BC_externav4.SLDPRT, asml_eslabon_BCv4.SLDPRT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]
2026-10-08 correciones CAD
    [asml_completo_v2v4.SLDASM, asml_eslabon_BC_externav4.SLDPRT, asml_eslabon_BC_externav4.STEP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]
2026-10-11 Interfaz web de telemetría en tiempo real (gui_hmi)
    Puente Python sin dependencias (UDP del ESP32 o datos simulados, reenviados
    por Server-Sent Events) y página sin bibliotecas: un gráfico por variable,
    cursor, pausa, consola de mensajes, lectura USB por Web Serial y grabación
    a CSV. Protocolo de líneas "nombre:valor" compatible con el Serial Plotter
    de Arduino. Registrado como HMI-001 en el backlog.
2026-10-16 pendulo invertido en Simulink con motor y LQR, y el motor real
    Simulink (simulacion/pendulo_invertido/):
    - pendulo_invertido_lqr.slx generado desde codigo, SOLO bloques nativos.
    - La planta va en forma matricial: q = [x; phi] como vector, matriz de masa
    armada por filas y un unico Divide matricial que resuelve M\rhs. Dos
    integradores vectoriales en vez de cuatro escalares.
    - Cinco areas en el nivel superior y cuatro dentro de la planta.
    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
2026-10-16 resolver a mano lo que el merge automatico no podia ver
    El merge con ff11061 (datasheets de electronica, de Matias) no dio conflicto,
    pero git solo compara lineas y habia dos choques de significado:
    - DOC-105 y PAR-003 estaban usados por los dos para items distintos. Los
    nuestros pasan a DOC-109 y PAR-004.
    - El PAR-003 de Matias pedia "conciliar CAD, masas y parametros de simulacion
    con los motores comprados" y figuraba pendiente. La parte de simulacion ya
    estaba hecha en este mismo trabajo, asi que queda EN CURSO con la parte de
    CAD abierta, en vez de dos filas diciendo lo mismo.
    - La nota del README que mandaba a leer las tablas historicas como si todavia
    nombraran al JGB37-520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
2026-10-17 electronica: Konnect 0.13.0 con KiCad 10.0.7 y prueba sin interfaz (ELE-027)
    - Registra Konnect en .mcp.json de la raíz (binario con SHA-256 verificado).
    - Proyecto de prueba cad/_prueba_mcp con evidencia de ERC y netlists.
    - La herramienta connect_pins cortocircuitó un resistor sin que el ERC
    lo detecte; se fija conectar con connect_to_net y verificar con el
    nuevo comparar_netlist.py contra conexiones esperadas.
    - Informe de la prueba y actualización del entorno, la skill y el flujo KiCad.
2026-10-17 electronica: MPU6050 en módulo de 8 pines y biblioteca de símbolos
    - Imagen de referencia de Matías en ROB-013, ficha e inventario actualizados.
    - Biblioteca cad/bibliotecas/segway_modulos.kicad_sym con el símbolo del
    módulo MPU6050; orden de pines leído de la serigrafía, provisorio.
    - Lista de datos faltantes al día (MPU6050, batería fija en 11,1 V).
2026-10-17 electronica: backlog y memoria al 17/10 (DEC-09 a DEC-11)
    - DEC-09: MPU6050 en módulo; DEC-10: 11,1 V fijo, batería se itera.
    - DEC-11: placa ESP32 de desarrollo provisoria, sin Blue Pill.
    - ELE-027 en curso con la parte en vivo pendiente; ELE-020 con biblioteca iniciada.
2026-10-17 electronica: commit y push al cerrar cada bloque, por pedido de Matías
2026-10-17 electronica: PCB editada en vivo con Konnect por la API de KiCad (ELE-027)
    - Actualizar PCB desde esquema, contorno, mover huellas, rutear y guardar
    por la API; DRC sin cortocircuitos y Gerbers generados.
    - La API solo responde si KiCad se abre desde el menú Inicio: con doble
    clic en el proyecto el canal desaparece al cerrarse la primera instancia.
    Regla de arranque agregada al flujo KiCad.
    - .history/ de KiCad 10 en .gitignore.
2026-10-17 electronica: generador de esquemas desde especificación JSON con Konnect
    Cliente MCP por stdio y generador que crea símbolos, ubica componentes,
    conecta por etiquetas, agrega PWR_FLAG y verifica con ERC y comparación
    de netlist. Probado con una especificación chica: ERC 0, netlist coincide.
2026-10-17 electronica: esquema de la placa base v0.2 (ELE-020)
    - Especificación eléctrica v0.2: 145 componentes, 54 nets, 6 símbolos de
    módulos (ESP32-DevKitC V4 provisoria, MPU6050, DRV8871, INA219, INA226,
    mini buck), tabla de GPIO y documento de diseño con 19 propuestas.
    - Esquema generado desde la especificación: ERC 0 errores y 0 avisos,
    netlist igual a la especificación; PDF y listas de materiales.
    - Generador: atributo DNP nativo y títulos de bloque.
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2026-10-17 electronica: esquema v0.3 con Blue Pill STM32F103C8T6 (ELE-020)
    - Especificación v0.3: 153 componentes, 63 nets, 7 símbolos de módulos;
    módulos enchufados en zócalos de 2,54 mm y motores en borneras (DEC-13).
    - Encoders en TIM2/TIM4, PWM de motores en TIM3, servos en TIM1, I2C2,
    rail 3V3 de periféricos con mini buck ROB-005.
    - Datasheet STM32F103 DS5319 y material de la Blue Pill archivados.
    - ERC 0 errores/0 avisos y netlist igual a la especificación.
2026-10-17 electronica: PCB casera de una capa y lista de supuestos (DEC-14, DEC-15)
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2026-10-20 electronica: división en placa de potencia y placa de lógica (DEC-17, v0.6)
    - Dos especificaciones v0.6 (potencia 48 componentes, lógica 12) con el
    cable IDC 2x8 J20; 13 nets del cable verificadas en ambas placas.
    - Esquemas generados: ERC 0 errores y netlist coincidente en las dos.
2026-10-20 electronica: PCB v0.1 de la placa de lógica, una cara, DRC limpio (ELE-032)
    - Ruteo a mano por topología (agente/placas/logica.py, TEC-04): DRC 0 errores,
    0 sin conectar, 0 de paridad; 2 puentes de alambre (3V3 17,8 mm y GND 7,6 mm).
    - Mapa de GPIO y cable J20 elegidos por geometría: columna par del IDC en línea
    con A1.15-22; SCL/SDA pasan por el MPU. D2 pasa a la placa de potencia (5V_MCU
    por el cable); J7 con extremos invertidos. Esquemas de lógica y potencia
    regenerados: ERC 0 y netlist coincidente.
    - construir_pcb.py con --placa y --fabricar: puentes fijos, áreas sin relleno,
    rótulos y escala en cobre, relleno con reglas reales, PDF 1:1, taladros.
    - Supuestos SUP-04/15/2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
2026-10-20 electronica: PCB v0.1 de la placa de potencia, una cara, DRC limpio (ELE-032)
    - Placa de potencia 150 x 110 mm: barra VM_BUS, lomo GND en estrella entre los
    pads de los fusibles, ramas por canal de motor, franja de servos y banda
    lógica. DRC 0 errores, 0 sin conectar, 0 de paridad; 7 puentes fijos.
    - Ruteo híbrido (TEC-05): esqueleto y bus I2C a mano (J20 -> A7 -> A5 ->
    corredor bajo los módulos -> A6), Freerouting solo para nets simples, vías
    prohibidas sobre componentes y poda automática de puentes redundantes.
    - Cable J20 y GPIO reordenados por geometría (VBAT en GPIO3, ALERT en GPIO8,
    columna par servos/IN); placa de lógica regenerada y re-verificada (0/0/0).
    - J20.11 si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
2026-10-26 electronica: expansión de la placa de lógica, tiras hembra junto a la ESP32-S3 (ELE-037)
    Pedido del equipo: pines hembra en paralelo a la controladora para sumar
    sensores (ultrasonido, infrarrojo).
    - J24 y J25: tiras hembra 1x22 pegadas a cada hilera de A1, pin a pin.
    Huellas propias con el courtyard recortado del lado de A1.
    - J26: tira hembra 1x6 de alimentación (GND, 3V3, 5V_MCU).
    - J20.11 sin conexión también en la lógica; rótulos de cobre bajados
    para que el relleno GND no quede partido.
    - generar_esquema.py: altura correcta de los conectores de una hilera
    (antes se pisaban las etiquetas y el comparador detectaba cortos).
    - ERC 0, netlist coincidente, DRC 0 errores / 0 sin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
2026-10-26 electronica: rótulos de cobre, revisión independiente y control eléctrico (ELE-039)
    - Rótulos de polaridad y de fusibles en el cobre de las dos placas,
    ubicados con ubicar_rotulos.py sin partir el relleno GND (SUP-14).
    - Revisión independiente del conexionado contra las fichas: módulos,
    cable, polaridades y niveles correctos. Riesgos nuevos: A7 y A8 entran
    girados y queman (SUP-80), aleta de Q1 con tensión (SUP-20), I2C junto
    a PWM en el cable (SUP-81).
    - auditoria_electrica.py: control repetible del sistema (cable, pines
    críticos, 5 V lejos de la ESP32, módulos girados, I2C, cuellos de
    pista, niveles). Informe: 0 fallas, 6 avisos.
    - J26 reordenado con GND en el medio; t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
2026-10-29 firmware: primer equilibrio en el piso (40 s) con LQR, odometría y rechaza banda
    Puesta en marcha del 29/10 con la placa en la PC de Joaquín (COM7) y el robot en el banco del malacate.
    - IMU: ejes del GY-521 de canto medidos en el robot (arriba +x, adelante -z, cabeceo +y), guía de
    conexión y prueba (firmware/docs/prueba_imu.md) y secuencia verificada: atrás -24°, 90° sin deriva.
    - IMU: el driver detecta el MPU-6050 dormido tras una caída de tensión y lo despierta; lecturas
    imposibles cuentan como fallidas; I2C a 100 kHz (sin errores con los motores); contadores en "get".
    - Encoders: estaban cruzados (corregido en board_pins.h) y son 899 cuentas por vuelta, medidas.
    - Motores: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
2026-10-31 electronica: v0.4 corregida tras la revisión independiente (ELE-042)
    - Mini buck (A8 y A9): huella con el tamaño real medido en las fotos
    (tipo Mini-360, pads a 14,3 x 8,9 mm; la anterior era de 19 x 14 y no
    entraba).
    - DRV8871: borneras de paso 5,0 mm (eran 3,5 mm; hasta 1,6 mm de error).
    - Potencia: W5 en diagonal, fuera de la carcasa de J20; A7 1,44 mm al
    este para no rozar J20; 5V rodea el pad OUT- de A8.
    - Lógica: título acortado («LOGICA v0.4») por el pad nuevo de A9.
    - Prueba de continuidad IN+/OUT+ de cada buck antes de alimentar.
    - DRC 0/0/0 en las dos placas, control eléctrico 0 fallas y 2 avisos;
    SUP-32, 35 y 37; registro de la revisión (DEC-18).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
2026-10-31 electronica: arreglos menores de la revisión acotada de la v0.4 (ELE-042)
    - Taladro de 1,5 mm en los pads de los mini buck: el lado corto se midió
    entre 8,4 y 9,2 mm en las fotos; absorbe el error hasta medir con calibre.
    - W5 de la potencia a 1,5 mm de la carcasa de J20.
    - INA226: contorno y courtyard a 18,7 mm de la tira (medida de las fotos).
    - Rótulos «IN»/«OUT» entre los pads de cada borde de los bucks.
    - Comentarios viejos de potencia.py corregidos.
    - DRC 0/0/0 en las dos placas, control eléctrico 0 fallas y 2 avisos.
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2026-11-01 electronica: potencia v0.7 con un UBEC por servo (ELE-048)
    Revisión del equipo sobre la v0.6: cada servo tiene su UBEC (DEC-21).
    - J16 -> servo DER (J14) con C8; J19 nueva -> servo IZQ (J13) con C9;
    buses de 6 V separados.
    - J15 de 4 bornes (1-2 GND, 3-4 VM_UBEC) para las dos entradas, F4
    compartido; placa de 124 x 77 mm. La lógica sigue en v0.6.
    - construir_pcb.py: OCULTAR_VALOR y TEXTOS_GUIA por placa.
    - ERC 0, netlist coincide, DRC 0/0/0, auditoría 0 fallas y 2 avisos;
    revisión independiente sin críticos, arreglos aplicados.
    - Guía, compras, supuestos v24 y PDF consolidado y completo v0.7.
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2026-11-11 segway_v02, joystick y página: Sharp con SharpDistSensor, altura, nivel de costado, giros de 1 grado y bugs de la interfaz (FW-031, FW-032, HMI-006)
    Firmware (grabado el 11/11; sin probar equilibrando):
    - Los dos Sharp con la biblioteca SharpDistSensor sin modificar
    (components/sharpdistsensor), un divisor por sensor, la altura sobre el piso
    en la telemetría (alt_mm, alt2_mm), el borde por altura y "set ircal".
    - Nivel de costado (nivel.c), apagado de fábrica: "set nivel".
    - "girar <grados>": giro corto medido con el giróscopo.
    Joystick: flechas izquierda/derecha giran 1 grado; R3 + L3 sostenidos, una
    demostración de control mal ajustado que se deshace al soltar y al armar.
    Págin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
